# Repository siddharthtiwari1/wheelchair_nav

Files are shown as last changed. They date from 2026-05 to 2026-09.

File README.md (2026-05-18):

# Autonomous Wheelchair Navigation

ROS 2 Jazzy navigation stack for a self-driving powered wheelchair: LiDAR and
depth-camera fusion, ZUPT/EKF odometry, SLAM Toolbox mapping, and Nav2.

The chair has a differential-drive base driven by an Arduino, a 2D RPLidar, and
three Intel RealSense depth cameras (the IMU is inside the front camera). It carries
a passenger, so the stack prioritises safe, predictable motion over speed. There are
two pipelines, sharing about 80% of their nodes: drive manually while SLAM Toolbox
builds a map, or give a goal pose and let Nav2 drive there on a saved map.

## Architecture

System architecture

Five layers. Data flows upward; only the velocity command flows back down to the
motors.

1. **Hardware & drivers**: Arduino motors/encoders, RPLidar S3, 3× RealSense, camera IMU.
2. **Sensor conditioning**: laser filter chain, IMU calibrate/bias/Madgwick/republish, scan fusion.
3. **State estimation**: ZUPT/EKF fuses wheel odometry and IMU into `/odometry/filtered` and `odom→base_link`.
4. **World frame**: SLAM Toolbox (mapping) or map_server + AMCL (navigation), producing `map→odom`.
5. **Behaviour**: navigation only: Nav2 behaviour tree, planner, controller, smoothed `/cmd_vel`.

TF tree: `map → odom → base_link → wheelchair_main → lidar → laser`, cameras
branching off `base_link`. `map→odom` is the periodic map correction (SLAM or AMCL),
`odom→base_link` the smooth dead-reckoning estimate from the ZUPT/EKF node. The
diff-drive controller's own odom TF is disabled so the two estimators do not collide.

## Packages

| Package | Responsibility |
|---|---|
| `wheelchair_bringup` | Top-level launch files |
| `wheelchair_navigation` | Nav2 parameter sets and behaviour trees |
| `wheelchair_localization` | `scan_fusion_v9`, AMCL / laser / SLAM configs |
| `wheelchair_zupt` | `zupt_node` (nav) and `robust_ekf_zupt_node` (slam) odometry |
| `wheelchair_description` | URDF/xacro, meshes, RViz configs |
| `wheelchair_firmware` | C++ `ros2_control` Arduino hardware interface |
| `wheelchair_mapping` | SLAM Toolbox launch/config helpers |
| `wc_control` | Diff-drive config and the 4-node IMU pipeline |
| `scripts` | Teleop, `cmd_vel` bridge, loggers, diagnostics |
| `rplidar_ros` | RPLidar S3 driver (vendored) |

## Hardware

| Item | Detail |
|---|---|
| Base | Differential drive, Arduino `/dev/ttyACM0`, 50 Hz wheel odometry |
| LiDAR | RPLidar S3, 360° 2D, ~10 Hz, `/scan` on `/dev/ttyUSB0` |
| Front camera | RealSense D455, depth 424×240 @ 6 Hz, sole IMU source |
| Side cameras | RealSense D455 (left, +90°), D435i (right, −90°), depth only |
| Geometry | Wheel radius 0.1524 m, separation 0.565 m, footprint 0.45 × 0.35 m |
| Velocity ceiling | 0.25 m/s, 0.35 rad/s at the smoother (capped again at 3 lower layers) |

## Build

Requires Ubuntu 24.04 with [ROS 2 Jazzy](https://docs.ros.org/en/jazzy/Installation.html).

```bash
git clone https://github.com/siddharthtiwari1/wheelchair_nav.git
cd wheelchair_nav

sudo apt update
sudo apt install \
    ros-jazzy-navigation2 ros-jazzy-nav2-bringup \
    ros-jazzy-robot-localization ros-jazzy-slam-toolbox \
    ros-jazzy-laser-filters ros-jazzy-realsense2-camera \
    ros-jazzy-realsense2-description ros-jazzy-imu-filter-madgwick \
    ros-jazzy-ros2-control ros-jazzy-ros2-controllers \
    ros-jazzy-controller-manager ros-jazzy-xacro

source /opt/ros/jazzy/setup.bash
colcon build --symlink-install
source install/setup.bash
```

The build uses `--symlink-install`, so editing a YAML, behaviour-tree XML, or RViz
config under `src/` takes effect on the next launch with no rebuild. `source
setup.bash` defines the `run_nav`, `run_slam`, and `run_localization` helpers.

USB device rules (one time):

```bash
sudo cp scripts/99-wheelchair-usb.rules /etc/udev/rules.d/
sudo udevadm control --reload-rules && sudo udevadm trigger
```

## Usage

| Helper | Launch | Purpose |
|---|---|---|
| `run_nav` | `wheelchair_fusion_nav.launch.py` | Autonomous navigation on a saved map |
| `run_slam` | `wheelchair_slam_mapping.launch.py` | Build a map by driving manually |

**Navigation.** Defaults: `map_name:=maps/h2.yaml`,
`nav2_params:=nav2_params_3cam_v29.yaml`, `bt_xml:=wheelchair_robust_nav_v3.xml`.

```bash
source setup.bash
run_nav
run_nav map_name:=/abs/path/to/your_map.yaml      # override any default
```

Send a goal with the RViz **2D Goal Pose** tool or the action interface:

```bash
ros2 action send_goal /navigate_to_pose nav2_msgs/action/NavigateToPose \
  "{pose: {header: {frame_id: 'map'}, pose: {position: {x: 1.0, y: 0.5}, orientation: {w: 1.0}}}}"
```

**Mapping.** `use_fused_slam` defaults to `true`, so a bare `run_slam` builds a
LiDAR + camera map. Press `Ctrl+C` to save; the session manager writes the map and
a rosbag.

```bash
run_slam                        # fused (slam_toolbox_fused_v21.yaml, /scan_fused)
run_slam use_fused_slam:=false  # lidar-only (slam_toolbox_motion_compensated_v2.yaml)
run_slam hospital_mode:=true    # long-range corridor config
```

## Pipeline

**Perception.** `/scan` passes a `laser_filters` chain (range + speckle; the 0.15 m
range floor also removes the chair's self-reflection) to `/scan_filtered`. A
four-node IMU pipeline turns the raw `/camera/imu` into a clean base-frame `/imu`:
startup calibrator (measures gyro bias from the first ~3 s of stillness), bias
corrector, Madgwick filter, base-frame republisher. `scan_fusion_v9` overlays the
three depth cameras onto the filtered scan, nearest valid return per angular bin,
0.10–1.80 m height window, range caps front 3.5 m / sides 3.0 m, ≥2 points/bin. Its
`/scan_fused` output feeds the costmaps.

**Odometry.** Both pipelines fuse `/wc_control/odom` and `/imu` into
`/odometry/filtered` and `odom→base_link`. Navigation uses `zupt_node`, a
complementary filter favouring the gyro with zero-velocity updates when still.
Mapping uses `robust_ekf_zupt_node`, a 6-state EKF `[x, y, θ, v, ω, gyro_bias]` with
zero-velocity updates and continuous gyro-bias recalibration.

**Localisation.** Mapping: SLAM Toolbox (sync) provides `/map` and `map→odom`.
Navigation: `map_server` serves the saved map and AMCL (`amcl_fusion.yaml`,
3000–10000 particles, on `/scan_filtered`) provides `map→odom`.

**Navigation.** Seven Nav2 servers: `SmacPlanner2D` global path,
`RegulatedPurePursuitController` at 20 Hz toward 0.25 m/s, `bt_navigator`,
`behavior_server`, smoother, velocity smoother, waypoint follower. Local costmap is
a rolling 5×5 m window (3-camera STVL + `/scan_fused` obstacle + 0.25 m inflation);
the global costmap adds the static map and 0.28 m inflation.

**Recovery.** A `RecoveryNode` (7 retries) wraps the plan/follow pipeline. On
failure it runs a backup-first sequence, since a loaded chair backs up more safely
than it spins: back up 0.15 m, clear costmaps, wait 2 s, spin +30°, back up 0.20 m,
spin −30°, then a 0.25 m backup as last resort. A new goal cancels recovery.

## Configuration

| File | Loaded by |
|---|---|
| `wc_control/config/wc_control_safe_v2.yaml` | `controller_manager` (diff-drive limits) |
| `wheelchair_localization/config/laser_filter_robust.yaml` | laser filter |
| `wheelchair_localization/config/slam_toolbox_fused_v21.yaml` | `slam_toolbox` (default fused) |
| `wheelchair_localization/config/slam_toolbox_motion_compensated_v2.yaml` | `slam_toolbox` (lidar-only) |
| `wheelchair_localization/config/amcl_fusion.yaml` | `amcl` |
| `wheelchair_navigation/config/nav2_params_3cam_v29.yaml` | the 7 Nav2 servers |
| `wheelchair_navigation/behavior_tree/wheelchair_robust_nav_v3.xml` | `bt_navigator` |

Config files (`*.yaml`, behaviour-tree `*.xml`, RViz configs) are never edited in
place. Each change creates a new versioned file, the launch default is repointed to
it, and the old file is kept for rollback. Source code is edited normally.

## Notes

- Keep the chair still for the first ~3 s after launch so the IMU calibrator can
  measure gyro bias; otherwise hard-coded defaults are used.
- The three cameras start staggered to avoid USB bandwidth contention; scan fusion
  waits until all three are up.
- Laser filter: only range and speckle are active. The angular, shadow,
  temporal-median, and box filters segfault on ROS 2 Jazzy and are disabled.
- `position_feedback` must stay `false` in the diff-drive config; differentiating
  position against slower Arduino data under-reports speed by ~35%.

| Symptom | Check |
|---|---|
| `Device busy` on launch | `pkill -9 -f ros; pkill -9 -f rviz; pkill -9 -f realsense; sleep 2` |
| AMCL not converging | `ros2 topic echo /map --once`, `ros2 topic hz /scan_filtered`, reset pose in RViz |
| Robot not moving | `ros2 lifecycle get /controller_server`, `ros2 topic hz /local_costmap/costmap` |
| Pose teleports in RViz | A second `odom→base_link` publisher; diff-drive `publish_odom_tf` must be `false` |

## Author

Siddharth Tiwari, IIT Mandi. s24035@students.iitmandi.ac.in

Released for academic and research use.

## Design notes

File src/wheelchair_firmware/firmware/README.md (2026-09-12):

# Arduino firmware for the wheelchair drive

These are the Arduino Mega sketches that run the hub motors, read the wheel
encoders, and talk to the ros2_control hardware interface in this package
(`src/wheelchair_interface.cpp`) over `/dev/ttyACM0` at 115200 baud.

They were written in the Arduino IDE sketchbook (`~/Arduino/`) and copied here
on 2026-09-12 so that the repository holds both halves of the drive layer.
The IDE copies remain the ones to open for flashing; keep the two in sync.

| Sketch | Written | Lines | Boot banner | Notes |
|---|---|---|---|---|
| `v3/v3.ino` | 2025-12-06 15:44 | 445 | `Wheelchair Controller v3.0 Ready` | 2 s hardware watchdog (`wdt_enable(WDTO_2S)`), atomic encoder reads, heap-free parsing, 20 Hz control loop, left-encoder sign fix |
| `final_control/final_control.ino` | 2025-12-06 17:27 | 571 | `Wheelchair Controller with PPM Support & Caster Swivel Prevention Ready` | no watchdog, adds 300 ms pivot on direction change (caster swivel prevention), prints a command help banner |

Both share: PID_v1 and Cytron SmartDriveDuo libraries, PPM radio input on pin 20
with a 500 ms timeout and priority over serial, relay on pin 53, encoders on
pins 18/19 (right) and 3/2 (left), wheel radius 0.1524 m, wheelbase 0.565 m,
PPM velocity caps of 1.0 m/s and 1.0 rad/s.

Which sketch is on the board has not been recorded. Read the banner on the
serial port at power-up (`screen /dev/ttyACM0 115200`) and note it here.

Related but unrelated: `wheelchair_nav/arduino/hub_motor_control/` is a bench
sketch with a 0.37 m wheel and is not the wheelchair firmware.

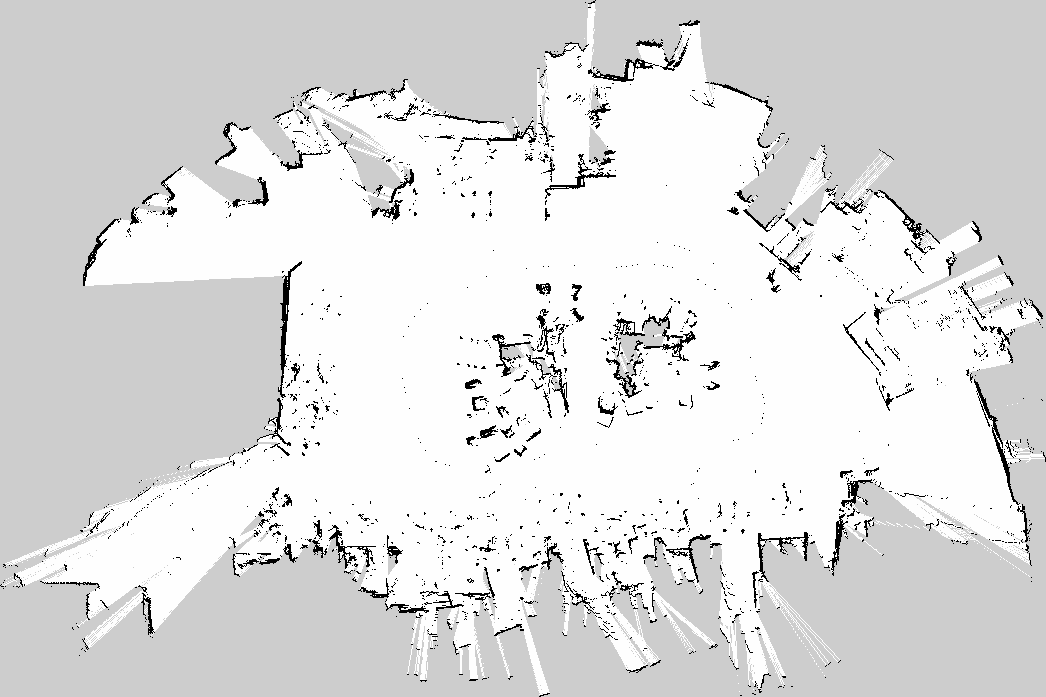
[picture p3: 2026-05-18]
maps/2026-03-06_lidar_only.png

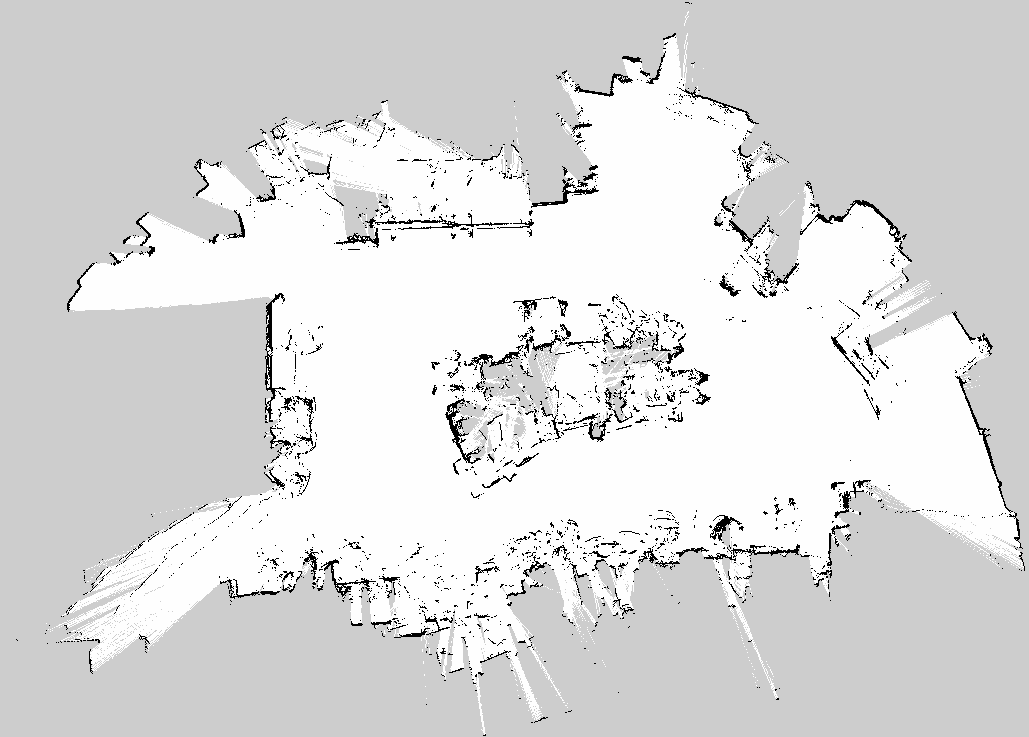
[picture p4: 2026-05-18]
maps/2026-03-06_camera_fused_2.png

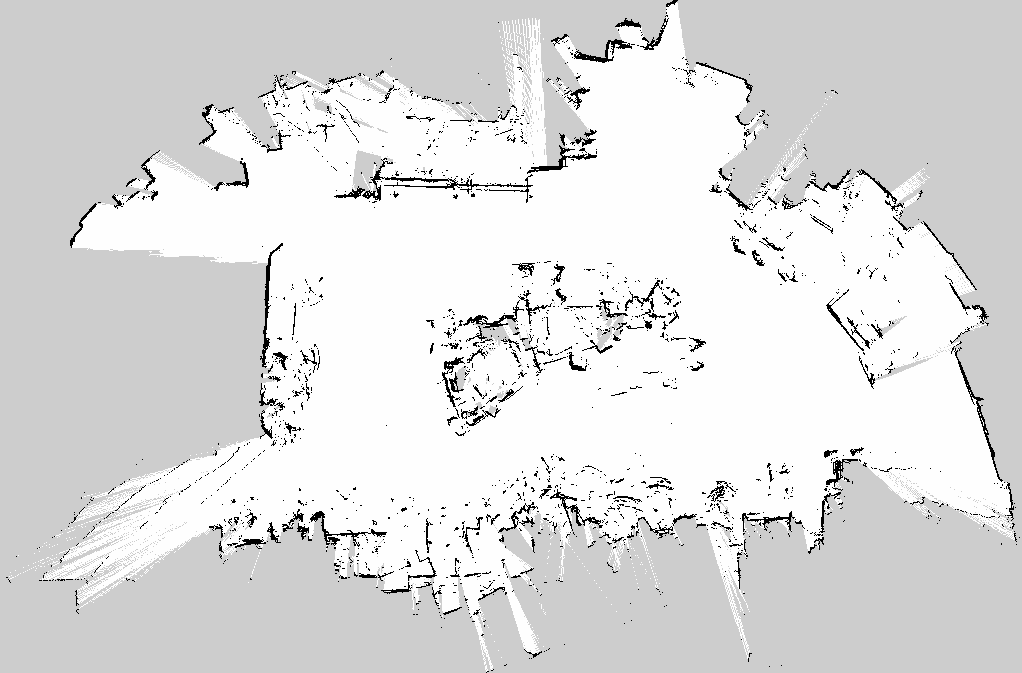
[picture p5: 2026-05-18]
maps/2026-03-06_camera_fused_1.png

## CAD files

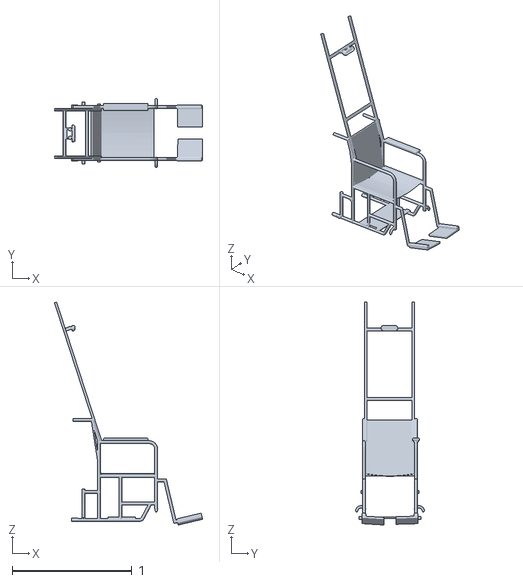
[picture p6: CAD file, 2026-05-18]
src/wheelchair_description/meshes/wheelchair_main.STL
1.24 x 0.579 x 1.87

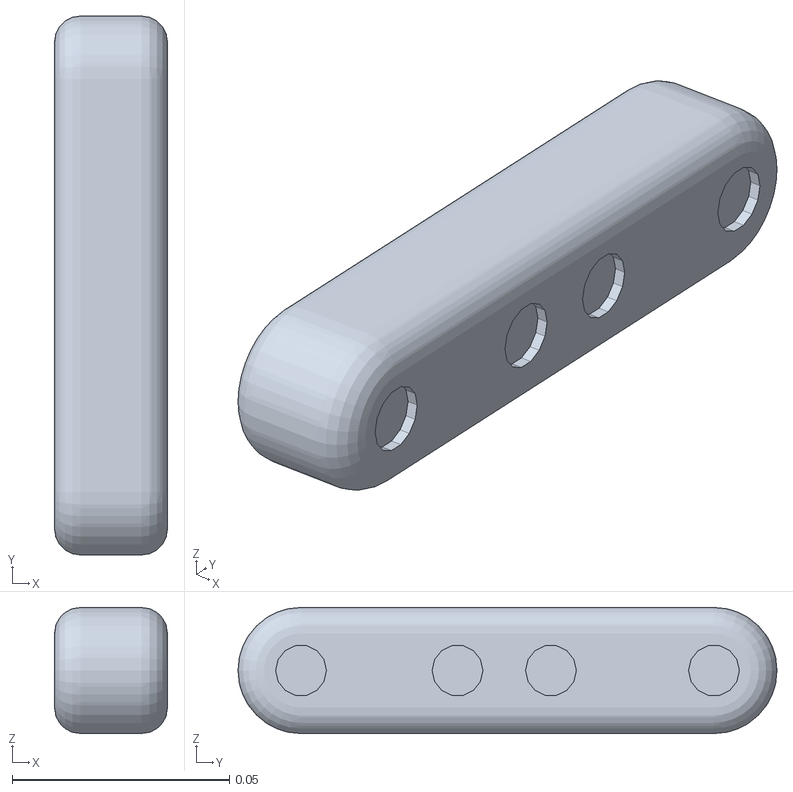
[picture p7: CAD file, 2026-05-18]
src/wheelchair_description/meshes/camera.STL
0.026 x 0.124 x 0.029

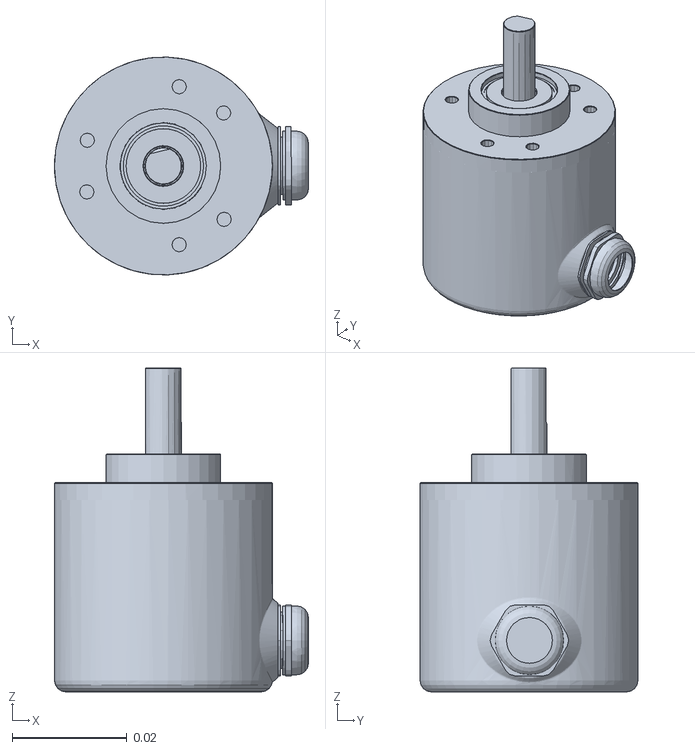
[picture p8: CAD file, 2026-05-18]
src/wheelchair_description/meshes/right_encoder.STL
0.0443 x 0.038 x 0.0565

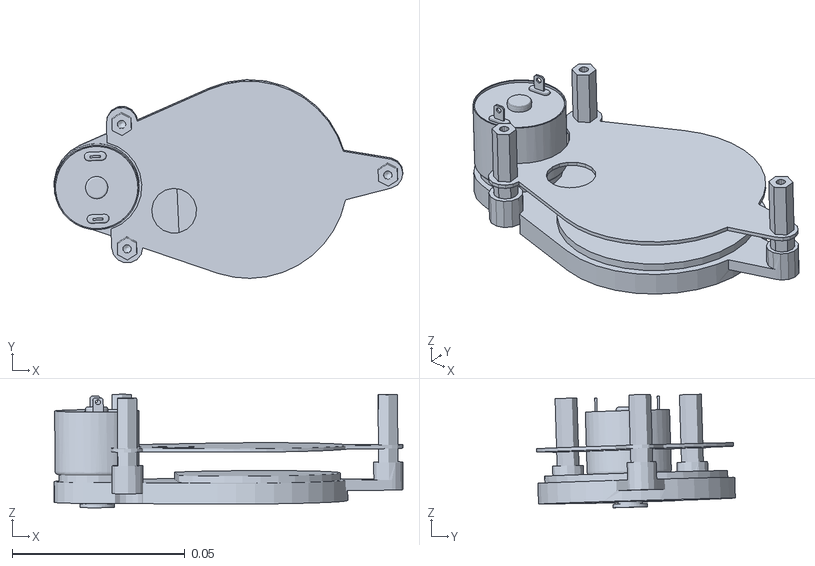
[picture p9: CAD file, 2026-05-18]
src/wheelchair_description/meshes/lidar.STL
0.101 x 0.0574 x 0.0328

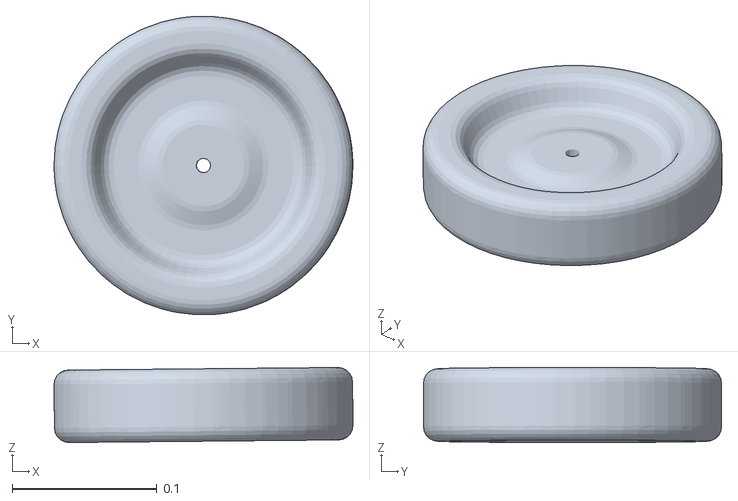
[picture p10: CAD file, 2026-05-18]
src/wheelchair_description/meshes/l_castor_wheel.STL
0.206 x 0.206 x 0.0518

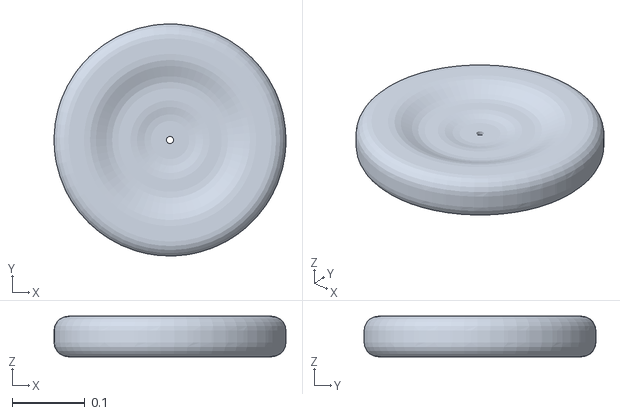
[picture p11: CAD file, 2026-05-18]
src/wheelchair_description/meshes/left_wheel.STL
0.32 x 0.32 x 0.056

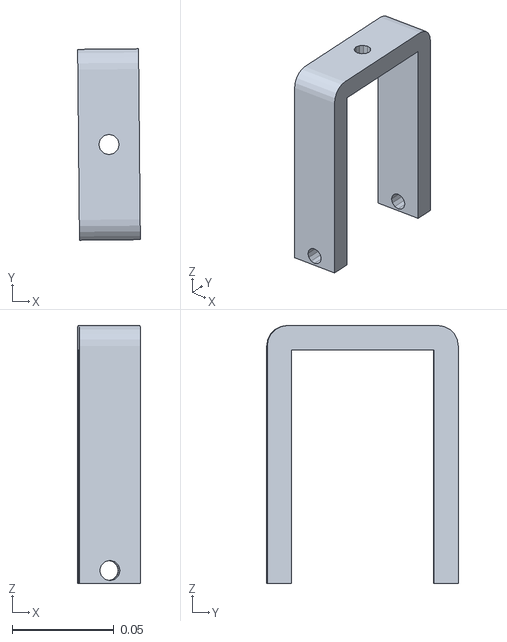
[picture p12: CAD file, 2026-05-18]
src/wheelchair_description/meshes/left_castor.STL
0.0309 x 0.0943 x 0.127

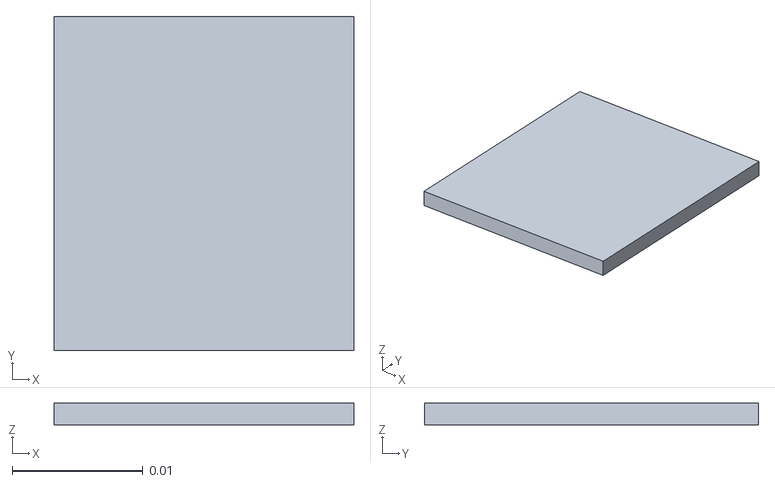
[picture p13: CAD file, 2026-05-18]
src/wheelchair_description/meshes/IMU.STL
0.0229 x 0.0255 x 0.00165

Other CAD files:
src/wheelchair_description/meshes/r_castor_wheel.STL
src/wheelchair_description/meshes/right_wheel.STL
src/wheelchair_description/meshes/left_encoder.STL
src/wheelchair_description/meshes/right_castor.STL

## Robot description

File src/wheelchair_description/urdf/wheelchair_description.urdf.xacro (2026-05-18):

<?xml version="1.0" encoding="utf-8"?>
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
<robot name="wheelchair_description" xmlns:xacro="http://ros.org/wiki/xacro">  
  
  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
  <xacro:arg name="is_ignition" default="true"/>

  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
  <xacro:arg name="is_sim" default="true"/>

  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
  <xacro:include filename="$(find wheelchair_description)/urdf/wc_gazebo.xacro" /> 
  
  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
  <xacro:include filename="$(find wheelchair_description)/urdf/wc_control.xacro" />

  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
  <xacro:include filename="$(find wheelchair_description)/urdf/cameras.xacro" />
  
  
  <link name="base_link">
  </link>
  
  <joint name="base_link_joint" type="fixed">
    <parent link="base_link"/>
    <child link="wheelchair_main"/>
    <origin xyz="0 0 0.2" rpy="0 0 0"/>
  </joint> 
  
  <link name="wheelchair_main">
    <inertial>
      <origin xyz="0.023007 0.0098899 0.35723" rpy="0 0 0" />
      <mass value="50" />
      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
    </inertial>
    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
  </link>
  <link name="left_wheel">
    <inertial>
      <origin xyz="0 -8.3267E-17 -0.016" rpy="0 0 0" />
      <mass value="3.5068" />
      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
    </inertial>
    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
  </link>
  <joint name="leftwheel" type="continuous">
    <origin xyz="-0.31984 0.285 -0.00794" rpy="-1.5708 0 0" />
    <parent link="wheelchair_main" />
    <child link="left_wheel" />
    <axis xyz="0 0 1" />
    <limit lower="-3.14" upper="3.14" effort="25" velocity="20" />
  </joint>
  <link name="left_encoder">
    <inertial>
      <origin xyz="-0.0001485 -4.9468E-06 0.038366" rpy="0 0 0" />
      <mass value="0.16" />
      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
    </inertial>
    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
  </link>
  <joint name="l_encoder_joint" type="fixed">
    <origin xyz="0 0 -0.015366" rpy="0 0 0" />
    <parent link="left_wheel" />
    <child link="left_encoder" />
    <axis xyz="0 0 0" />
  </joint>
  <link name="right_wheel">
    <inertial>
      <origin xyz="-1.11022302462516E-16 3.88578058618805E-16 0.0159999999999998" rpy="0 0 0" />
      <mass value="3.50680611696861" />
      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
    </inertial>
    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
  </link>
  <joint name="rightwheel" type="continuous">
    <origin xyz="-0.31984 -0.285 -0.00794" rpy="-1.5708 0 0" />
    <parent link="wheelchair_main" />
    <child link="right_wheel" />
    <axis xyz="0 0 1" />
    <limit lower="-3.14" upper="3.14" effort="25" velocity="30" />
  </joint>
  <link name="right_encoder">
    <inertial>
      <origin xyz="0.00014858 -3.8114E-07 -0.038366" rpy="0 0 0" />
      <mass value="0.16" />
      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
    </inertial>
    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
  </link>
  <joint name="r_encoder_joint" type="fixed">
    <origin xyz="0 0 0.015366" rpy="0 0 0" />
    <parent link="right_wheel" />
    <child link="right_encoder" />
    <axis xyz="0 0 0" />
  </joint>
  
  <link name="left_castor">
    <inertial>
      <origin xyz="0 2.7756E-17 -0.050849" rpy="0 0 0" />
      <mass value="0.11252" />
      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
    </inertial>
    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
  </link>
  <joint name="leftcastor" type="fixed">
    <origin xyz="0.29024 0.27855 0.053019" rpy="0 0 0" />
    <parent link="wheelchair_main" />
    <child link="left_castor" />
    <axis xyz="0 0 -1" />  
      
    <dynamics damping="0.0" friction="0.0"/>
  </joint>

  <link name="l_castor_wheel">
    <inertial>
      <origin xyz="0.0004998 0 -0.052109" rpy="0 0 0" />
      <mass value="1.0084" />
      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
    </inertial>
    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
  </link>
  <joint name="leftcastorwheel" type="fixed">
    <origin xyz="-0.00049873 0.051998 -0.12062" rpy="-1.5708 0 0" />
    <parent link="left_castor" />
    <child link="l_castor_wheel" />
    <axis xyz="0 0 -1" />
    <dynamics damping="0.01" friction="0.0"/>
  </joint>
  <link name="right_castor">
    <inertial>
      <origin xyz="0 2.2204E-16 -0.050849" rpy="0 0 0" />
      <mass value="0.11252" />
      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
    </inertial>
    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
  </link>
  <joint name="rightcastor" type="fixed">
    <origin xyz="0.29024 -0.29047 0.053019" rpy="0 0 0" />
    <parent link="wheelchair_main" />
    <child link="right_castor" />
    <axis xyz="0 0 -1" />
    <dynamics damping="0.0" friction="0.0"/>
  </joint>

  <link name="r_castor_wheel">
    <inertial>
      <origin xyz="-0.00062904 -4.1633E-17 0.046953" rpy="0 0 0" />
      <mass value="1.0084" />
      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
    </inertial>
    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
  </link>
  <joint name="rcastorwheel" type="fixed">
    <origin xyz="0.00062961 -0.046996 -0.12062" rpy="-1.5708 0 0" />
    <parent link="right_castor" />
    <child link="r_castor_wheel" />
    <axis xyz="0 0 -1" />
    <dynamics damping="0.01" friction="0.0"/>
  </joint>
  <link name="lidar">
    <inertial>
      <origin xyz="-0.017408 -0.0015843 0.028267" rpy="0 0 0" />
      <mass value="0.17" />
      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
    </inertial>
    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
  </link>
  <joint name="lidar_joint" type="fixed">
    <origin xyz="0.475 0.12 -0.13" rpy="0 0 0" />
    <parent link="wheelchair_main" />
    <child link="lidar" />
    <axis xyz="0 0 0" />
  </joint>
  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
  <link name="laser"/>
  <joint name="laser_joint" type="fixed">
    <origin xyz="0 0 0" rpy="0 0 3.14159265358979"/>
    <parent link="lidar"/>
    <child link="laser"/>
  </joint>
  <link name="camera">
    <inertial>
      <origin xyz="-0.01312 -0.00011035 3.4198E-05" rpy="0 0 0" />
      <mass value="0.083345" />
      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
    </inertial>
    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
  </link>
  <joint name="camera_joint" type="fixed">
    <origin xyz="-0.41 0 1.34" rpy="0 0 0" />
    <parent link="wheelchair_main" />
    <child link="camera" />
    <axis xyz="0 0 0" />
  </joint>
  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
  <link name="camera_link">
    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
  </link>
  
  <joint name="camera_link_joint" type="fixed">
    <origin xyz="0 0 0" rpy="0 0 0"/>
    <parent link="camera"/>
    <child link="camera_link"/>
  </joint>

  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
  <link name="camera_color_optical_frame"/>

  <joint name="camera_color_optical_joint" type="fixed">
    <origin xyz="0 0 0" rpy="-1.5708 0 -1.5708"/>
    <parent link="camera_link"/>
    <child link="camera_color_optical_frame"/>
  </joint>

  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
  <link name="camera_depth_optical_frame"/>

  <joint name="camera_depth_optical_joint" type="fixed">
    <origin xyz="0 0 0" rpy="-1.5708 0 -1.5708"/>
    <parent link="camera_link"/>
    <child link="camera_depth_optical_frame"/>
  </joint>

  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
  <link name="camera_depth_frame"/>

  <joint name="camera_depth_frame_joint" type="fixed">
    <origin xyz="0 0 0" rpy="0 0 0"/>
    <parent link="camera_link"/>
    <child link="camera_depth_frame"/>
  </joint>

  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
  <link name="IMU">
    <inertial>
      <origin xyz="0 0 -0.000825" rpy="0 0 0" />
      <mass value="0.025" />
      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
    </inertial>
    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
  </link>
  
  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
  <joint name="IMU_joint" type="fixed">
    <origin xyz="-0.01174 -0.00552 0.0051" rpy="0 0 0" />
    <parent link="camera_link" />
    <child link="IMU" />
  </joint>

  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
  <link name="camera_imu_optical_frame"/>
  
  <joint name="camera_imu_optical_joint" type="fixed">
    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
    <origin xyz="0 0 0" rpy="-1.5708 0 -1.5708"/>
    <parent link="IMU"/>
    <child link="camera_imu_optical_frame"/>
  </joint>
  
  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
  <link name="imu_link"/>
  
  <joint name="imu_link_joint" type="fixed">
    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
    <origin xyz="0 0 0" rpy="0 1.5708 1.5708"/>
    <parent link="camera_imu_optical_frame"/>
    <child link="imu_link"/>
  </joint>

  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
  <link name="imu_link_simple"/>
  
  <joint name="imu_link_simple_joint" type="fixed">
    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
    <origin xyz="-0.42 0 1.35" rpy="0 0 0"/>
    <parent link="base_link"/>
    <child link="imu_link_simple"/>
  </joint>

</robot>

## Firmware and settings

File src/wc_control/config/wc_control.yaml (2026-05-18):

controller_manager:
  ros__parameters:
    update_rate: 100  # Hz
    
    # Controller definitions
    joint_state_broadcaster:
      type: joint_state_broadcaster/JointStateBroadcaster
    
    wc_control:
      type: diff_drive_controller/DiffDriveController
    
    imu_sensor_broadcaster:
      type: imu_sensor_broadcaster/IMUSensorBroadcaster
    
    simple_velocity_controller:
      type: velocity_controllers/JointGroupVelocityController

# Differential Drive Controller Configuration
wc_control:
  ros__parameters:
    # Joint names - FIXED to use leftwheel/rightwheel
    left_wheel_names: ['leftwheel']
    right_wheel_names: ['rightwheel']

    # CRITICAL: Odometry feedback settings
    # open_loop: false = Use encoder feedback (closed-loop control)
    # position_feedback: false = Use velocity states directly (not differentiated from position)
    # WHY: Arduino sends at 20Hz, controller runs at 100Hz. With position_feedback: true,
    #      the controller differentiates position with its own dt, causing 35% velocity underestimation.
    #      With position_feedback: false, it uses the velocity values directly from hardware interface.
    open_loop: false
    position_feedback: false

    # Use stamped velocity commands (TwistStamped)
    use_stamped_vel: true

    # Publish rates and covariances
    publish_rate: 50.0
    pose_covariance_diagonal: [0.001, 0.001, 1.0e-3, 1.0e-3, 1.0e-3, 0.01]
    twist_covariance_diagonal: [0.001, 0.001, 1.0e-3, 1.0e-3, 1.0e-3, 0.01]
    
    # Wheel parameters - Physical measurements (calibrate after fixing timing bug)
    wheel_separation: 0.565  # Physical measurement - recalibrate with fixed code!
    wheel_radius: 0.1524     # ACTUAL 6-inch wheels (304.8mm diameter / 2)
    # No multipliers - use correct physical parameters
    # If odometry is wrong, the root cause must be fixed in:
    #   1. Arduino firmware (encoder direction/CPR)
    #   2. Hardware interface (velocity sign conventions)
    wheel_separation_multiplier: 1.0
    left_wheel_radius_multiplier: 1.0
    right_wheel_radius_multiplier: 1.0
    
    # Command timeout
    cmd_vel_timeout: 0.5
    
    # Frame IDs (must match URDF)
    base_frame_id: base_link  # Matches wheelchair URDF
    odom_frame_id: odom
    
    # Publishing options
    publish_limited_velocity: true
    publish_wheel_data: true
    enable_odom_tf: false  # DISABLED - EKF publishes odom->base_link (prevents TF conflict!)

    # Velocity and acceleration limits
    linear:
      x:
        has_velocity_limits: true
        max_velocity: 2.0  # m/s
        min_velocity: -1.0 # m/s
        has_acceleration_limits: true
        max_acceleration: 1.5  # m/s^2
        min_acceleration: -1.0 # m/s^2
        has_jerk_limits: false
        max_jerk: 5.0  # m/s^3
    
    angular:
      z:
        has_velocity_limits: true
        max_velocity: 3.0  # rad/s
        has_acceleration_limits: true
        max_acceleration: 2.0  # rad/s^2
        has_jerk_limits: false
        max_jerk: 3.0  # rad/s^3

# Simple Velocity Controller Configuration (alternative/backup)
simple_velocity_controller:
  ros__parameters:
    joints:
      - leftwheel
      - rightwheel
    interface_name: velocity
    command_interfaces:
      - velocity
    state_interfaces:
      - position
      - velocity

# Joint State Broadcaster Configuration
joint_state_broadcaster:
  ros__parameters:
    joints:
      - leftwheel
      - rightwheel

# IMU Sensor Broadcaster Configuration
imu_sensor_broadcaster:
  ros__parameters:
    sensor_name: imu
    frame_id: base_link  # Frame where IMU is mounted
    topic_name: ~/imu  # Will publish to /imu_sensor_broadcaster/imu

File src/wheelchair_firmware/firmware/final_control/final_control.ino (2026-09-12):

#include <PID_v1.h>
#include <Cytron_SmartDriveDuo.h>

// ================== PPM CONFIG ==================
#define PPM_PIN 20          // PPM signal input pin
#define CHANNELS 8         // Number of PPM channels

volatile uint16_t ppmValues[CHANNELS];
volatile uint8_t ppmIndex = 0;
volatile unsigned long lastMicros = 0;

// PPM variables
int ch1, ch2;
bool ppm_active = false;
unsigned long last_ppm_time = 0;
const unsigned long PPM_TIMEOUT = 500; // 500ms timeout for PPM signal

// Encoder pins
int encoderPin1R = 18;
int encoderPin2R = 19;
int encoderPin1L = 3;
int encoderPin2L = 2;

// Relay Pin
int relayPin = 53;

// Motor driver pins
#define IN1 7
#define AN1 5
#define AN2 4
#define IN2 6

Cytron_SmartDriveDuo smartDriveDuo(PWM_INDEPENDENT, IN1, IN2, AN1, AN2);

// Encoder variables
volatile int lastEncodedL = 0;
volatile long encoderValueL = 0;
volatile int lastEncodedR = 0;
volatile long encoderValueR = 0;

// Wheel specifications
const long CPR = 10000;
const float WHEEL_RADIUS = 0.1524; // 6 inches
const float WHEELBASE = 0.565; // 57 cm
const float MAX_ANGULAR_VEL = 17.59; // rad/s
const float MAX_LINEAR_VEL = 2.68; // m/s (WHEEL_RADIUS * MAX_ANGULAR_VEL)

// PPM velocity limits (can be different from serial limits for safety)
const float PPM_MAX_LINEAR_VEL = 1.0;   // 1 m/s max for PPM
const float PPM_MAX_ANGULAR_VEL = 1.0;  // 1 rad/s max for PPM

// Timing
unsigned long last_millis = 0;
const unsigned long interval = 50;
long lastEncoderL = 0;
long lastEncoderR = 0;

// CASTER SWIVEL PREVENTION
bool pivot_mode = false;
unsigned long pivot_start_time = 0;
const unsigned long PIVOT_DURATION = 300; // 300ms pivot duration
const float PIVOT_ANGULAR_VEL = 2.0; // rad/s for pivot turn
float prev_linear_velocity = 0.0;
float stored_linear_cmd = 0.0;
float stored_angular_cmd = 0.0;

// TRIPLE COMMAND PARSING SYSTEM
enum CommandMode {
  WHEEL_MODE,    // rp5.0,lp3.0,
  CMDVEL_MODE,   // x:0.5,t:0.1,
  PPM_MODE       // PPM transmitter input
};

CommandMode current_mode = WHEEL_MODE;

// Command parsing variables
bool is_right_wheel_cmd = false;
bool is_left_wheel_cmd = false;
bool is_linear_cmd = false;
bool is_angular_cmd = false;
bool is_right_wheel_forward = true;
bool is_left_wheel_forward = true;
char value[] = "00.00";
uint8_t value_idx = 0;
String right_wheel_sign = "p";
String left_wheel_sign = "p";

// Velocity variables
double right_wheel_cmd_vel = 0.0;
double left_wheel_cmd_vel = 0.0;
double right_wheel_target = 0.0;
double left_wheel_target = 0.0;
double right_wheel_meas_vel = 0.0;
double left_wheel_meas_vel = 0.0;
double right_wheel_cmd = 0.0;
double left_wheel_cmd = 0.0;

// cmd_vel variables
double linear_x = 0.0;
double angular_z = 0.0;

// Acceleration limiting
const double MAX_ACCEL = 5.0;
double filtered_right_vel = 0.0;
double filtered_left_vel = 0.0;
const double FILTER_ALPHA = 0.8;

// PID gains
double Kp_r = 7.0, Ki_r = 8.0, Kd_r = 0.15;
double Kp_l = 7.2, Ki_l = 8.5, Kd_l = 0.15;

// Manual PID variables
double right_integral = 0.0, left_integral = 0.0;
double right_prev_error = 0.0, left_prev_error = 0.0;
double right_prev_meas = 0.0, left_prev_meas = 0.0;

// ================== CASTER SWIVEL PREVENTION ==================
bool needsPivot(float current_linear, float prev_linear) {
  // Check if we're changing from forward to backward or vice versa
  return (prev_linear > 0.1 && current_linear < -0.1) ||
         (prev_linear < -0.1 && current_linear > 0.1);
}

void startPivot(float linear_cmd, float angular_cmd) {
  pivot_mode = true;
  pivot_start_time = millis();
  stored_linear_cmd = linear_cmd;
  stored_angular_cmd = angular_cmd;

  // Determine pivot direction based on desired angular velocity
  // If no angular command, pivot in the direction that requires less rotation
  float pivot_angular = (angular_cmd != 0) ? (angular_cmd > 0 ? PIVOT_ANGULAR_VEL : -PIVOT_ANGULAR_VEL) : PIVOT_ANGULAR_VEL;

  // Execute pivot turn (no linear motion)
  cmdVelToWheels(0.0, pivot_angular);
}

bool updatePivot() {
  if (!pivot_mode) return false;

  if (millis() - pivot_start_time >= PIVOT_DURATION) {
    // Pivot complete, execute stored command
    pivot_mode = false;
    cmdVelToWheels(stored_linear_cmd, stored_angular_cmd);
    prev_linear_velocity = stored_linear_cmd;
    return false;
  }
  return true; // Still pivoting
}

// ================== PPM INTERRUPT ==================
void ppmISR() {
  unsigned long now = micros();
  unsigned long diff = now - lastMicros;
  lastMicros = now;

  if (diff > 3200) {
    ppmIndex = 0;
  } else {
    if (ppmIndex < CHANNELS) {
      ppmValues[ppmIndex] = diff;
      ppmIndex++;
    }
  }
}

// ================== PPM PROCESSING ==================
void processPPMInput() {
  // Check if PPM signal is active
  unsigned long current_time = millis();

  // Map PPM values to channels
  ch1 = ppmValues[0]; // Channel 1 - Angular (Rotation)
  ch2 = ppmValues[1]; // Channel 2 - Throttle (Linear)

  // Check for valid PPM signal (typical range 1000-2000)
  if (ch1 > 900 && ch1 < 2100 && ch2 > 900 && ch2 < 2100) {
    ppm_active = true;
    last_ppm_time = current_time;
    current_mode = PPM_MODE;

    // Apply deadband (center stick positions)
    int ch1_filtered = ch1;
    int ch2_filtered = ch2;

    if (ch1 > 1460 && ch1 < 1540) ch1_filtered = 1500;
    if (ch2 > 1460 && ch2 < 1540) ch2_filtered = 1500;

    // Constrain inputs to valid range for safety
    ch1_filtered = constrain(ch1_filtered, 1000, 2000);
    ch2_filtered = constrain(ch2_filtered, 1000, 2000);

    // Map Channel 2 to Linear Velocity
    float linear_velocity = ((float)(ch2_filtered - 1500) / 500.0) * PPM_MAX_LINEAR_VEL;
    linear_velocity = constrain(linear_velocity, -PPM_MAX_LINEAR_VEL, PPM_MAX_LINEAR_VEL);

    // Map Channel 1 to Angular Velocity
    float angular_velocity = ((float)(1500 - ch1_filtered) / 500.0) * PPM_MAX_ANGULAR_VEL;
    angular_velocity = constrain(angular_velocity, -PPM_MAX_ANGULAR_VEL, PPM_MAX_ANGULAR_VEL);

    // Check if pivot is needed for direction change
    if (needsPivot(linear_velocity, prev_linear_velocity) && !pivot_mode) {
      startPivot(linear_velocity, angular_velocity);
      return;
    }

    // If we're in pivot mode, continue pivoting
    if (updatePivot()) {
      return;
    }

    // Convert to wheel velocities using differential drive kinematics
    float left_linear_component = linear_velocity / WHEEL_RADIUS;
    float right_linear_component = linear_velocity / WHEEL_RADIUS;
    float angular_component = (angular_velocity * WHEELBASE / 2.0) / WHEEL_RADIUS;

    float left_wheel_vel = left_linear_component - angular_component;
    float right_wheel_vel = right_linear_component + angular_component;

    // Apply limits
    left_wheel_vel = constrain(left_wheel_vel, -MAX_ANGULAR_VEL, MAX_ANGULAR_VEL);
    right_wheel_vel = constrain(right_wheel_vel, -MAX_ANGULAR_VEL, MAX_ANGULAR_VEL);

    // Check for command changes to reset integrals
    if((right_wheel_cmd_vel * right_wheel_vel < 0) || (abs(right_wheel_vel - right_wheel_cmd_vel) > 3.0)) {
      right_integral = 0.0;
      right_wheel_target = 0.0;
    }

    if((left_wheel_cmd_vel * left_wheel_vel < 0) || (abs(left_wheel_vel - left_wheel_cmd_vel) > 3.0)) {
      left_integral = 0.0;
      left_wheel_target = 0.0;
    }

    // Update command velocities
    right_wheel_cmd_vel = right_wheel_vel;
    left_wheel_cmd_vel = left_wheel_vel;
    prev_linear_velocity = linear_velocity;

  } else {
    // Check for PPM timeout
    if (ppm_active && (current_time - last_ppm_time > PPM_TIMEOUT)) {
      ppm_active = false;
      pivot_mode = false; // Reset pivot mode on signal loss
      // Stop the wheelchair when PPM signal is lost
      right_wheel_cmd_vel = 0.0;
      left_wheel_cmd_vel = 0.0;
      prev_linear_velocity = 0.0;
      Serial.println("PPM signal lost - stopping");
    }
  }
}

// Encoder functions (unchanged)
void updateEncoderL(){
  int MSB = digitalRead(encoderPin1L);
  int LSB = digitalRead(encoderPin2L);
  int encoded = (MSB << 1) | LSB;
  int sum = (lastEncodedL << 2) | encoded;

  if(sum == 0b1101 || sum == 0b0100 || sum == 0b0010 || sum == 0b1011) encoderValueL++;
  if(sum == 0b1110 || sum == 0b0111 || sum == 0b0001 || sum == 0b1000) encoderValueL--;

  lastEncodedL = encoded;
}

void updateEncoderR(){
  int MSB = digitalRead(encoderPin1R);
  int LSB = digitalRead(encoderPin2R);
  int encoded = (MSB << 1) | LSB;
  int sum = (lastEncodedR << 2) | encoded;

  if(sum == 0b1101 || sum == 0b0100 || sum == 0b0010 || sum == 0b1011) encoderValueR++;
  if(sum == 0b1110 || sum == 0b0111 || sum == 0b0001 || sum == 0b1000) encoderValueR--;

  lastEncodedR = encoded;
}

// Forward kinematics: Convert cmd_vel to wheel velocities
void cmdVelToWheels(double linear, double angular) {
  // Check if pivot is needed for direction change
  if (needsPivot(linear, prev_linear_velocity) && !pivot_mode) {
    startPivot(linear, angular);
    return;
  }

  // Differential drive kinematics
  double right_vel = (linear + angular * WHEELBASE/2.0) / WHEEL_RADIUS;
  double left_vel = (linear - angular * WHEELBASE/2.0) / WHEEL_RADIUS;

  // Apply limits
  right_wheel_cmd_vel = constrain(right_vel, -MAX_ANGULAR_VEL, MAX_ANGULAR_VEL);
  left_wheel_cmd_vel = constrain(left_vel, -MAX_ANGULAR_VEL, MAX_ANGULAR_VEL);

  // Reset integrals on new command
  right_integral = 0.0;
  left_integral = 0.0;
  right_wheel_target = 0.0;
  left_wheel_target = 0.0;

  prev_linear_velocity = linear;
}

// Manual PID with anti-windup
double computePID(double setpoint, double measurement, double &integral,
                 double &prev_error, double &prev_meas, double Kp, double Ki, double Kd, double dt) {

  double error = setpoint - measurement;
  integral += error * dt;
  integral = constrain(integral, -100.0/Ki, 100.0/Ki);

  double derivative = -(measurement - prev_meas) / dt;
  double output = Kp * error + Ki * integral + Kd * derivative;

  double clamped_output = constrain(output, -100.0, 100.0);
  if (output != clamped_output) {
    integral = (clamped_output - Kp * error - Kd * derivative) / Ki;
  }

  prev_error = error;
  prev_meas = measurement;
  return clamped_output;
}

// Smooth acceleration limiting
double rampVelocity(double current, double target, double max_accel, double dt) {
  double diff = target - current;
  double max_change = max_accel * dt;

  if (abs(diff) <= max_change) {
    return target;
  } else {
    return current + (diff > 0 ? max_change : -max_change);
  }
}

void setup() {
  Serial.begin(115200);

  // PPM input setup
  pinMode(PPM_PIN, INPUT);
  attachInterrupt(digitalPinToInterrupt(PPM_PIN), ppmISR, RISING);

  // Relay initialization
  pinMode(relayPin, OUTPUT);
  digitalWrite(relayPin, HIGH);
  delay(5000);
  digitalWrite(relayPin, LOW);

  // Encoder setup
  pinMode(encoderPin1L, INPUT_PULLUP);
  pinMode(encoderPin2L, INPUT_PULLUP);
  pinMode(encoderPin1R, INPUT_PULLUP);
  pinMode(encoderPin2R, INPUT_PULLUP);

  attachInterrupt(digitalPinToInterrupt(encoderPin1L), updateEncoderL, CHANGE);
  attachInterrupt(digitalPinToInterrupt(encoderPin2L), updateEncoderL, CHANGE);
  attachInterrupt(digitalPinToInterrupt(encoderPin1R), updateEncoderR, CHANGE);
  attachInterrupt(digitalPinToInterrupt(encoderPin2R), updateEncoderR, CHANGE);

  filtered_right_vel = 0.0;
  filtered_left_vel = 0.0;
  last_millis = millis();

  Serial.println("Wheelchair Controller with PPM Support & Caster Swivel Prevention Ready");
  Serial.println("Commands:");
  Serial.println("Individual: rp5.0,lp3.0,");
  Serial.println("cmd_vel: x:0.5,t:0.1,");
  Serial.println("PPM: CH1=Angular, CH2=Throttle");
  Serial.println("PPM Priority: Will override serial when active");
  Serial.println("Caster Swivel Prevention: 300ms pivot on direction change");
}

void loop() {
  // Process PPM input first (highest priority)
  processPPMInput();

  // Handle pivot mode updates for serial commands
  if (!ppm_active && pivot_mode) {
    updatePivot();
  }

  // Only process serial commands if PPM is not active
  if (!ppm_active && Serial.available()) {
    char chr = Serial.read();

    // Detect command type
    if(chr == 'r' || chr == 'l') {
      current_mode = WHEEL_MODE;
    } else if(chr == 'x' || chr == 't') {
      current_mode = CMDVEL_MODE;
    }

    // WHEEL MODE PARSING
    if(current_mode == WHEEL_MODE) {
      if(chr == 'r') {
        is_right_wheel_cmd = true;
        is_left_wheel_cmd = false;
        value_idx = 0;
      }
      else if(chr == 'l') {
        is_right_wheel_cmd = false;
        is_left_wheel_cmd = true;
        value_idx = 0;
      }
      else if(chr == 'p') {
        if(is_right_wheel_cmd) {
          is_right_wheel_forward = true;
          right_wheel_sign = "p";
        }
        else if(is_left_wheel_cmd) {
          is_left_wheel_forward = true;
          left_wheel_sign = "p";
        }
      }
      else if(chr == 'n') {
        if(is_right_wheel_cmd) {
          is_right_wheel_forward = false;
          right_wheel_sign = "n";
        }
        else if(is_left_wheel_cmd) {
          is_left_wheel_forward = false;
          left_wheel_sign = "n";
        }
      }
      else if(chr == ',') {
        if(is_right_wheel_cmd) {
          double new_cmd = atof(value);
          if(!is_right_wheel_forward) new_cmd = -new_cmd;

          if((right_wheel_cmd_vel * new_cmd < 0) || (abs(new_cmd - right_wheel_cmd_vel) > 3.0)) {
            right_integral = 0.0;
            right_wheel_target = 0.0;
          }

          right_wheel_cmd_vel = constrain(new_cmd, -MAX_ANGULAR_VEL, MAX_ANGULAR_VEL);
        }
        else if(is_left_wheel_cmd) {
          double new_cmd = atof(value);
          if(!is_left_wheel_forward) new_cmd = -new_cmd;

          if((left_wheel_cmd_vel * new_cmd < 0) || (abs(new_cmd - left_wheel_cmd_vel) > 3.0)) {
            left_integral = 0.0;
            left_wheel_target = 0.0;
          }

          left_wheel_cmd_vel = constrain(new_cmd, -MAX_ANGULAR_VEL, MAX_ANGULAR_VEL);
        }

        // Reset value buffer
        value_idx = 0;
        value[0] = '0'; value[1] = '0'; value[2] = '.';
        value[3] = '0'; value[4] = '0'; value[5] = '\0';
      }
      else if(value_idx < 5) {
        value[value_idx] = chr;
        value_idx++;
      }
    }

    // CMD_VEL MODE PARSING
    else if(current_mode == CMDVEL_MODE) {
      if(chr == 'x') {
        is_linear_cmd = true;
        is_angular_cmd = false;
        value_idx = 0;
      }
      else if(chr == 't') {
        is_linear_cmd = false;
        is_angular_cmd = true;
        value_idx = 0;
      }
      else if(chr == ':') {
        // Start reading value after ':'
        value_idx = 0;
      }
      else if(chr == ',') {
        if(is_linear_cmd) {
          linear_x = constrain(atof(value), -MAX_LINEAR_VEL, MAX_LINEAR_VEL);
        }
        else if(is_angular_cmd) {
          angular_z = constrain(atof(value), -10.0, 10.0); // Max 10 rad/s angular

          // Apply forward kinematics when we get angular command
          cmdVelToWheels(linear_x, angular_z);
        }

        // Reset value buffer
        value_idx = 0;
        value[0] = '0'; value[1] = '0'; value[2] = '.';
        value[3] = '0'; value[4] = '0'; value[5] = '\0';
      }
      else if((chr >= '0' && chr <= '9') || chr == '.' || chr == '-') {
        if(value_idx < 5) {
          value[value_idx] = chr;
          value_idx++;
        }
      }
    }
  }

  // CONTROL LOOP
  unsigned long current_millis = millis();
  if(current_millis - last_millis >= interval) {
    float deltaT = (current_millis - last_millis) / 1000.0;

    // Calculate raw velocities
    long deltaCountsL = encoderValueL - lastEncoderL;
    long deltaCountsR = encoderValueR - lastEncoderR;

    double raw_right_vel = (deltaCountsR / (float)CPR) * (2.0 * PI / deltaT);
    double raw_left_vel = -(deltaCountsL / (float)CPR) * (2.0 * PI / deltaT);

    // Apply filtering
    filtered_right_vel = FILTER_ALPHA * raw_right_vel + (1.0 - FILTER_ALPHA) * filtered_right_vel;
    filtered_left_vel = FILTER_ALPHA * raw_left_vel + (1.0 - FILTER_ALPHA) * filtered_left_vel;

    right_wheel_meas_vel = filtered_right_vel;
    left_wheel_meas_vel = filtered_left_vel;

    // Apply smooth acceleration limiting
    right_wheel_target = rampVelocity(right_wheel_target, right_wheel_cmd_vel, MAX_ACCEL, deltaT);
    left_wheel_target = rampVelocity(left_wheel_target, left_wheel_cmd_vel, MAX_ACCEL, deltaT);

    // Manual PID with anti-windup
    right_wheel_cmd = computePID(right_wheel_target, right_wheel_meas_vel, right_integral,
                                right_prev_error, right_prev_meas, Kp_r, Ki_r, Kd_r, deltaT);

    left_wheel_cmd = computePID(left_wheel_target, left_wheel_meas_vel, left_integral,
                               left_prev_error, left_prev_meas, Kp_l, Ki_l, Kd_l, deltaT);

    // Handle zero commands
    if(abs(right_wheel_target) < 0.1) {
      right_wheel_cmd = 0.0;
      right_integral = 0.0;
    }
    if(abs(left_wheel_target) < 0.1) {
      left_wheel_cmd = 0.0;
      left_integral = 0.0;
    }

    // Update signs for feedback
    right_wheel_sign = (right_wheel_meas_vel >= 0) ? "p" : "n";
    left_wheel_sign = (left_wheel_meas_vel >= 0) ? "p" : "n";

    // Apply motor commands
    smartDriveDuo.control((int)right_wheel_cmd, -(int)left_wheel_cmd);

    // Enhanced feedback - show current mode and velocities
    String mode_indicator = "";
    if (ppm_active) {
      mode_indicator = "[PPM] ";
    } else if (current_mode == CMDVEL_MODE) {
      mode_indicator = "[CMD_VEL] ";
    } else {
      mode_indicator = "[WHEEL] ";
    }

    if (pivot_mode) {
      mode_indicator += "[PIVOT] ";
    }

    String encoder_read = mode_indicator + "r" + right_wheel_sign + String(abs(right_wheel_meas_vel), 2) +
                         ",l" + left_wheel_sign + String(abs(left_wheel_meas_vel), 2) + ",";
    Serial.println(encoder_read);

    // Update for next iteration
    lastEncoderL = encoderValueL;
    lastEncoderR = encoderValueR;
    last_millis = current_millis;
  }
}

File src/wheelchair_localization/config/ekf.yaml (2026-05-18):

ekf_filter_node:
    ros__parameters:
      # The frequency, in Hz, at which the filter will output a position estimate. Note that the filter will not begin
      # computation until it receives at least one message from one of the inputs. It will then run continuously at the
      # frequency specified here, regardless of whether it receives more measurements. Defaults to 30 if unspecified.
      frequency: 50.0  # Increased from 30Hz to reduce localization lag (33ms -> 20ms)

      # ekf_localization_node and ukf_localization_node both use a 3D omnidirectional motion model. If this parameter is
      # set to true, no 3D information will be used in your state estimate. Use this if you are operating in a planar
      # environment and want to ignore the effect of small variations in the ground plane that might otherwise be detected
      # by, for example, an IMU. Defaults to false if unspecified.
      two_d_mode: true

      # Whether to broadcast the transformation over the /tf topic. Defaults to true if unspecified.
      publish_tf: true

      # REP-105 (http://www.ros.org/reps/rep-0105.html) specifies four principal coordinate frames: base_link, odom, map, and
      # earth. base_link is the coordinate frame that is affixed to the robot. Both odom and map are world-fixed frames.
      # The robot's position in the odom frame will drift over time, but is accurate in the short term and should be
      # continuous. The odom frame is therefore the best frame for executing local motion plans. The map frame, like the odom
      # frame, is a world-fixed coordinate frame, and while it contains the most globally accurate position estimate for your
      # robot, it is subject to discrete jumps, e.g., due to the fusion of GPS data or a correction from a map-based
      # localization node. The earth frame is used to relate multiple map frames by giving them a common reference frame.
      # ekf_localization_node and ukf_localization_node are not concerned with the earth frame.
      # Here is how to use the following settings:
      # 1. Set the map_frame, odom_frame, and base_link frames to the appropriate frame names for your system.
      #     1a. If your system does not have a map_frame, just remove it, and make sure "world_frame" is set to the value of
      #         odom_frame.
      # 2. If you are fusing continuous position data such as wheel encoder odometry, visual odometry, or IMU data, set
      #   "world_frame" to your odom_frame value. This is the default behavior for robot_localization's state estimation nodes.
      # 3. If you are fusing global absolute position data that is subject to discrete jumps (e.g., GPS or position updates
      # from landmark observations) then:
      #     3a. Set your "world_frame" to your map_frame value
      #     3b. MAKE SURE something else is generating the odom->base_link transform. Note that this can even be another state
      #         estimation node from robot_localization! However, that instance should *not* fuse the global data.
      map_frame: map              # Defaults to "map" if unspecified
      odom_frame: odom            # Defaults to "odom" if unspecified
      base_link_frame: base_link  # Standard ROS frame for wheelchair
      world_frame: odom           # Defaults to the value of odom_frame if unspecified

      

      # IMU Configuration - RealSense D455 via wheelchair republisher with calibration
      imu0: /imu
      # Wheelchair-specific sensor fusion - ROBUST configuration:
      # - Odometry: Position (x,y) and velocity (vx) - accurate from wheel encoders
      # - IMU: Yaw orientation and yaw angular velocity - stable orientation
      # - NO IMU ACCELERATION: too noisy for position estimation
      # Order: x, y, z, roll, pitch, yaw, vx, vy, vz, vroll, vpitch, vyaw, ax, ay, az
      # Original: IMU yaw + yaw rate; no IMU position/accel
      imu0_config: [false, false, false,    # x, y, z position (not from IMU)
                    false, false, true,     # yaw orientation from IMU
                    false, false, false,    # x_vel, y_vel, z_vel
                    false, false, true,     # yaw_vel from IMU
                    false, false, false]    # accelerations off

      imu0_differential: false  # Use absolute values since republisher handles zeroing
      imu0_relative: false
      imu0_queue_size: 5
      imu0_remove_gravitational_acceleration: false  # Already handled by republisher
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

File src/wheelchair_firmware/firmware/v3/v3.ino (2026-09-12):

/*
 * WHEELCHAIR CONTROLLER v3.0
 * ===========================
 *
 * Based on v2 "industry grade" but with critical odometry fix:
 * - Left encoder publishes physical forward as positive (no double negation).
 * - Keeps PID/motor sign handling separate from what is sent to ROS.
 *
 * Other features retained:
 * - Atomic encoder reads
 * - Watchdog timer (2s)
 * - Safe parsing buffers (no heap allocation in loop)
 * - deltaT validation
 * - Clean serial protocol for ROS parsing
 */

#include <PID_v1.h>
#include <Cytron_SmartDriveDuo.h>
#include <avr/wdt.h>

// ================== PPM CONFIG ==================
#define PPM_PIN 20
#define CHANNELS 8

volatile uint16_t ppmValues[CHANNELS];
volatile uint8_t ppmIndex = 0;
volatile unsigned long lastMicros = 0;

int ch1, ch2;
bool ppm_active = false;
unsigned long last_ppm_time = 0;
const unsigned long PPM_TIMEOUT = 500;

// ================== PIN DEFINITIONS ==================
const int encoderPin1R = 18;
const int encoderPin2R = 19;
const int encoderPin1L = 3;
const int encoderPin2L = 2;
const int relayPin = 53;

#define IN1 7
#define AN1 5
#define AN2 4
#define IN2 6

Cytron_SmartDriveDuo smartDriveDuo(PWM_INDEPENDENT, IN1, IN2, AN1, AN2);

// ================== ENCODER VARIABLES ==================
volatile int lastEncodedL = 0;
volatile long encoderValueL = 0;
volatile int lastEncodedR = 0;
volatile long encoderValueR = 0;

// ================== WHEEL SPECIFICATIONS ==================
const long CPR = 10000;
const float WHEEL_RADIUS = 0.1524f;  // 6 inches
const float WHEELBASE = 0.565f;       // meters
const float MAX_ANGULAR_VEL = 17.59f;
const float MAX_LINEAR_VEL = 2.68f;

// PPM velocity limits (safety)
const float PPM_MAX_LINEAR_VEL = 1.0f;
const float PPM_MAX_ANGULAR_VEL = 1.0f;

// ================== TIMING ==================
unsigned long last_millis = 0;
const unsigned long CONTROL_INTERVAL = 50;  // 20 Hz
const float MIN_DELTA_T = 0.001f;
const float MAX_DELTA_T = 0.5f;
long lastEncoderL = 0;
long lastEncoderR = 0;

// ================== CASTER SWIVEL PREVENTION ==================
bool pivot_mode = false;
unsigned long pivot_start_time = 0;
const unsigned long PIVOT_DURATION = 300;
const float PIVOT_ANGULAR_VEL = 2.0f;
float prev_linear_velocity = 0.0f;
float stored_linear_cmd = 0.0f;
float stored_angular_cmd = 0.0f;

// ================== COMMAND MODE ==================
enum CommandMode { WHEEL_MODE, CMDVEL_MODE, PPM_MODE };
CommandMode current_mode = WHEEL_MODE;

// ================== COMMAND PARSING ==================
char value_buffer[12];
uint8_t value_idx = 0;
const uint8_t VALUE_BUFFER_MAX = 10;

bool is_right_wheel_cmd = false;
bool is_left_wheel_cmd = false;
bool is_linear_cmd = false;
bool is_angular_cmd = false;
bool is_right_wheel_forward = true;
bool is_left_wheel_forward = true;

// ================== VELOCITY VARIABLES ==================
double right_wheel_cmd_vel = 0.0;
double left_wheel_cmd_vel = 0.0;
double right_wheel_target = 0.0;
double left_wheel_target = 0.0;
double right_wheel_meas_vel = 0.0;
double left_wheel_meas_vel = 0.0;
double right_wheel_cmd = 0.0;
double left_wheel_cmd = 0.0;

// cmd_vel variables
double linear_x = 0.0;
double angular_z = 0.0;

// ================== FILTERING & ACCELERATION ==================
const double MAX_ACCEL = 5.0;
double filtered_right_vel = 0.0;
double filtered_left_vel = 0.0;
const double FILTER_ALPHA = 0.8;

// ================== PID GAINS ==================
double Kp_r = 7.0, Ki_r = 8.0, Kd_r = 0.15;
double Kp_l = 7.2, Ki_l = 8.5, Kd_l = 0.15;

// Manual PID state
double right_integral = 0.0, left_integral = 0.0;
double right_prev_error = 0.0, left_prev_error = 0.0;
double right_prev_meas = 0.0, left_prev_meas = 0.0;

// ================== ATOMIC ENCODER READ ==================
void readEncodersAtomic(long &leftVal, long &rightVal) {
  noInterrupts();
  leftVal = encoderValueL;
  rightVal = encoderValueR;
  interrupts();
}

// ================== CASTER SWIVEL PREVENTION ==================
bool needsPivot(float current_linear, float prev_linear) {
  return (prev_linear > 0.1f && current_linear < -0.1f) ||
         (prev_linear < -0.1f && current_linear > 0.1f);
}

void startPivot(float linear_cmd, float angular_cmd) {
  pivot_mode = true;
  pivot_start_time = millis();
  stored_linear_cmd = linear_cmd;
  stored_angular_cmd = angular_cmd;

  float pivot_angular = (angular_cmd != 0.0f)
                            ? (angular_cmd > 0.0f ? PIVOT_ANGULAR_VEL : -PIVOT_ANGULAR_VEL)
                            : PIVOT_ANGULAR_VEL;
  cmdVelToWheels(0.0, pivot_angular);
}

bool updatePivot() {
  if (!pivot_mode) return false;
  if (millis() - pivot_start_time >= PIVOT_DURATION) {
    pivot_mode = false;
    cmdVelToWheels(stored_linear_cmd, stored_angular_cmd);
    prev_linear_velocity = stored_linear_cmd;
    return false;
  }
  return true;
}

// ================== PPM INTERRUPT ==================
void ppmISR() {
  unsigned long now = micros();
  unsigned long diff = now - lastMicros;
  lastMicros = now;

  if (diff > 3200) {
    ppmIndex = 0;
  } else if (ppmIndex < CHANNELS) {
    ppmValues[ppmIndex] = diff;
    ppmIndex++;
  }
}
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

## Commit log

2026-05-18 Wheelchair autonomous navigation workspace
    ROS2 Jazzy workspace for an autonomous differential-drive wheelchair:
    SLAM Toolbox mapping, AMCL localization, Nav2 planning/control, EKF +
    ZUPT odometry fusion, and 3-camera + LiDAR scan fusion.
    Packages: wheelchair_bringup, wheelchair_navigation, wheelchair_localization,
    wheelchair_description, wheelchair_firmware, wheelchair_mapping, wheelchair_zupt,
    wheelchair_e2e, wheelchair_mono_depth, wc_control, kinoflow_controller, scripts,
    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
    [IMU.STL, camera.STL, cameras.xacro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]
2026-05-18 Trim repo to core navigation stack
    Remove side tools and ML pipelines (cable_trace_deploy, ground_truth_labeling,
    kinoflow_controller, wheelchair_e2e, wheelchair_mono_depth) and gitignore them.
    Repo now scopes to the deployed SLAM/localization/Nav2 navigation workspace.
2026-05-18 Tighten README: minimal, plain, source-accurate
2026-09-12 wheelchair_firmware: add the two Arduino drive sketches (v3, final_control) with README
    The sketches lived only in the Arduino IDE sketchbook (~/Arduino/). The package
    held the host-side ros2_control interface but not the firmware it talks to.
    Both December 2025 sketches are added verbatim; the README records how they
    differ and that the flashed one is still to be confirmed from the boot banner.
    Claude-Session: https://claude.ai/code/session_01Y87TH7fyYjz28hKR2q8XG3
